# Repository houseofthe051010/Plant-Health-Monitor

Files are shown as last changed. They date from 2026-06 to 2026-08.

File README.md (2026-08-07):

# ESP32 Plant Health Monitor Rover

I built this to sample soil health from my garden to help plnat growth. This is just a prototype, not a reliable version yet, I will build another iteration but this is what I have currently. It is a fun educational toy to play with though.

## Features

* Autonomous
* Two-servo tank drive
* Seven servos total
  * Two continuous-rotation drive servos
  * Four arm position servos
  * One sample chamber closing servo
* Soil electrical conductivity measurement
* Temperature, humidity, pressure, and light measurements
* Ultrasound distance measurement
* Blackbox sensor data logging onboard esp32 flash

## Proof Pictures

Here is the demo video I have on the robot:

https://www.youtube.com/shorts/W9_TdJyh92A

### CAD Prototype

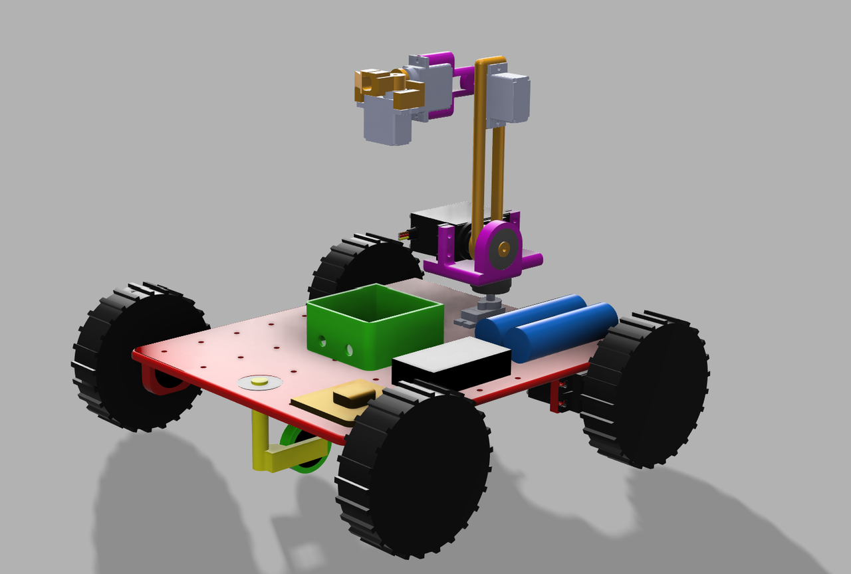
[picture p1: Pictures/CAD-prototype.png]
CAD Prototype


### Circuit Schematic

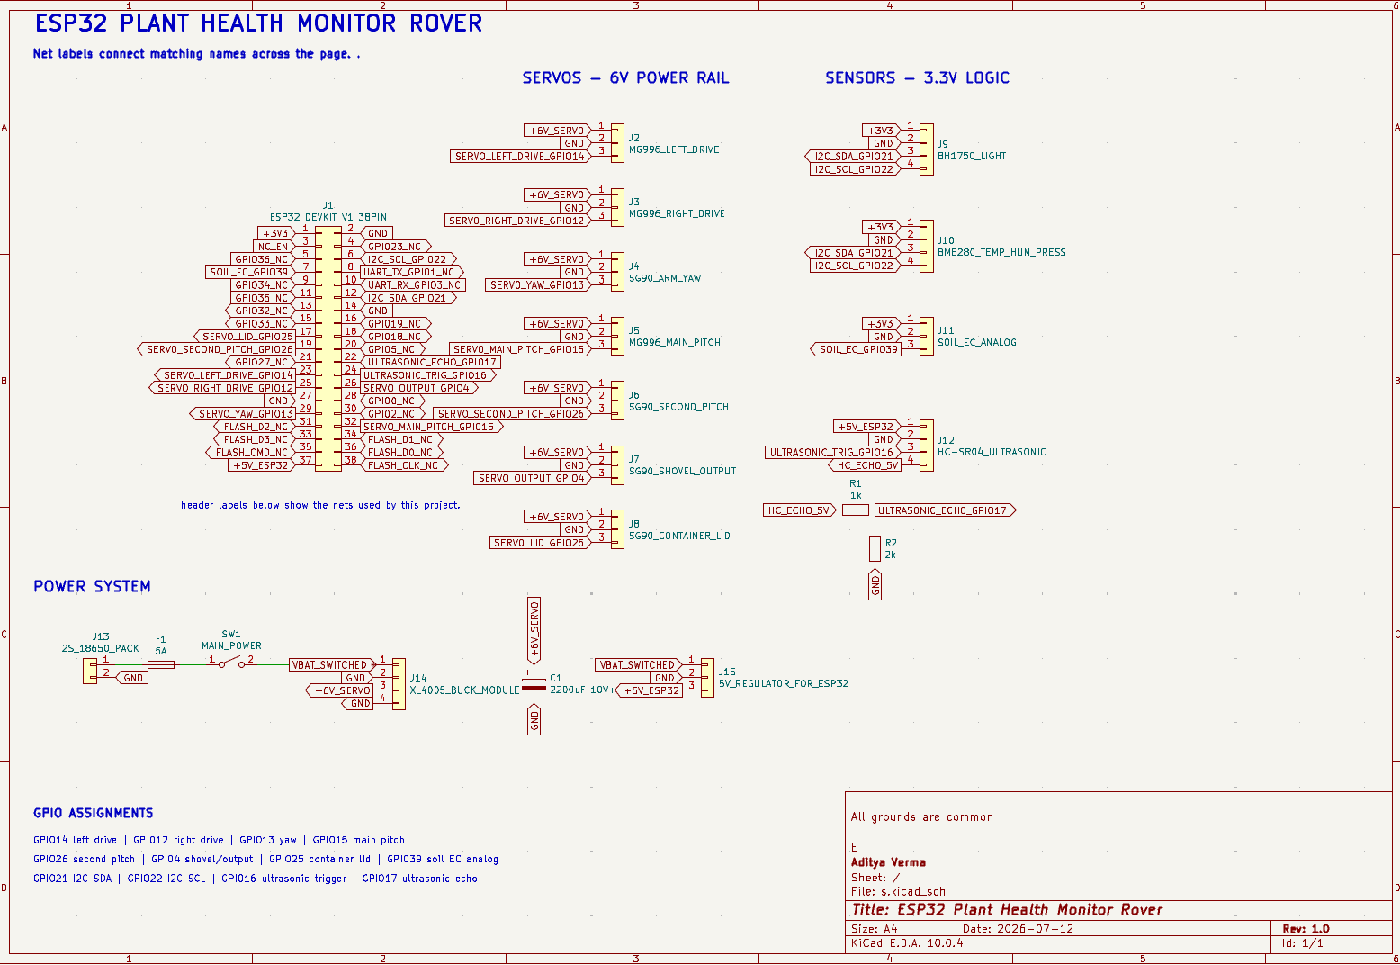
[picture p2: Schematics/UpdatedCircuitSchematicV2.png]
Updated Circuit Schematic


### Real-Life Prototype

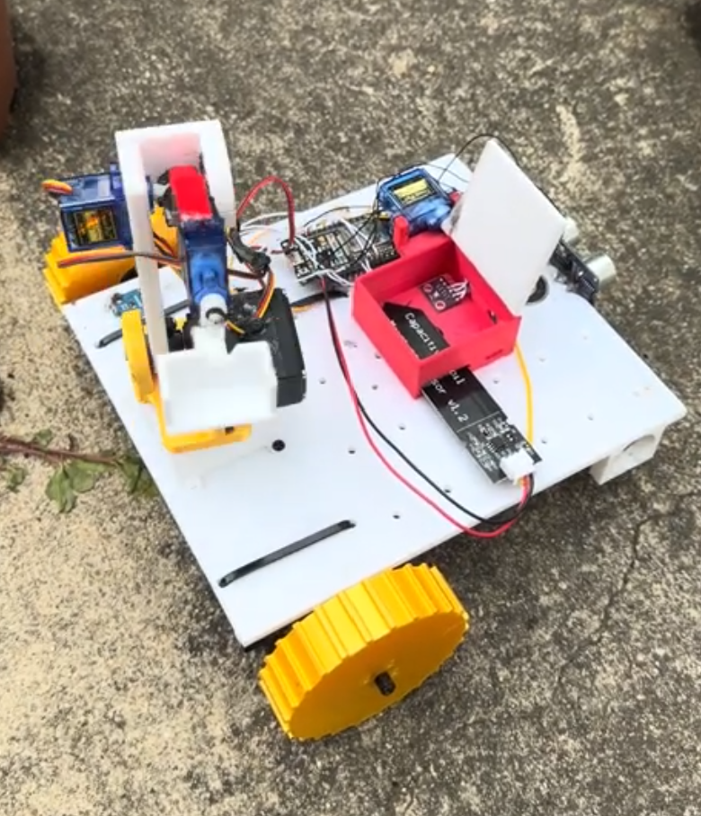
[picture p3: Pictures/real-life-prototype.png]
Real-Life Prototype


## Hardware Description

The rover utilizes ESP32 microcontroller. Tank drive is controlled using two PWM outputs, acting as continuous-rotation servos. Soil collection uses five additional PWM outputs to actuate servos of the arm and close the sample chamber.

Sensors include a BH1750 light sensor, a BME280 environmental sensor, an HC-SR04 ultrasound distance sensor, and an analog soil electrical conductivity sensor. Both BH1750 and BME280 are on the same I2C bus.

All the hardware data is logged to the ESP32's internal micropython filesystem and can be exported over USB.

## Bill of materials

| Category |  Quantity | Part | Purchase Link | Estimated Price |
| --- | ---: | --- | --- | ---: |
| Electronics | 1 | ESP32 | [AliExpress](https://www.aliexpress.us/item/3256812360578716.html) | $4.67 |
| Actuator | 2 | MG996 | [AliExpress](https://www.aliexpress.us/item/3256804365417662.html) | $9.28 |
| Actuator | 1 | MG996 180 Degree | [AliExpress](https://www.aliexpress.us/item/3256804365417662.html) | $4.64 |
| Actuator | 5 | SG90 | [AliExpress](https://www.aliexpress.us/item/3256806107378152.html) | $4.95 |
| Sensor | 1 | Ambient light sensor  | [AliExpress](https://www.aliexpress.us/item/3256809513329235.html) | $3.00 |
| Sensor | 1 | Environmental sensor  | [AliExpress](https://www.aliexpress.us/item/3256812547404758.html) | $5.85 |
| Sensor | 1 | Ultrasonic sensor | [AliExpress](https://www.aliexpress.us/item/3256810017345486.html) | $1.25 |
| Sensor | 1 | Soil EC sensor | [AliExpress](https://www.aliexpress.us/item/3256811685769454.html) | $13.29 |
| Power | 1 | Buck converter | [AliExpress](https://www.aliexpress.us/item/3256806558389509.html) | $1.46 |
| Power | 2 | 18650 cell | [AliExpress](https://www.aliexpress.us/item/3256811867524654.html) | $3.35 (2 of 16-pack at $26.77) |
| Power | 1 | 2S battery holder | [AliExpress](https://www.aliexpress.us/item/3256809135366720.html) | $0.99 |
| Power | 1 | Power switch | [AliExpress](https://www.aliexpress.us/item/3256807619399290.html) | $0.16 used (1 of 10-pack at $1.64) |
| Power | 1 | 2S battery charger | [AliExpress](https://www.aliexpress.us/item/3256805668198456.html) | $0.99 |
| Mechanical  | 5 | Ball bearing | [AliExpress](https://www.aliexpress.us/item/3256805609422387.html) | $8.06 (5-pack) |
| Mechanical  | As needed | M3 fasteners | [AliExpress](https://www.aliexpress.us/item/3256809672273859.html) | $14.88 assortment kit |
| Fabricated  | As needed | 3D filament allowance | [AliExpress](https://www.aliexpress.us/item/3256806989098121.html) | $3.00 |

## GPIO Mapping (needed for final wiring)

| Component | Purpose | ESP32 GPIO |
| --- | --- | ---: |
| Left drive motor | Drivetrain | 14 |
| Right drive motor | Drivetrain | 12 |
| Base yaw motor | Collection arm rotation | 13 |
| Base pitch motor | Main collection arm lift | 15 |
| Second pitch motor | Secondary collection arm | 26 |
| Shovel rotation motor | Soil collector/collector | 4 |
| Sample chamber motor  | Opens/closes sample chamber | 25 |
| Soil EC sensor | Analog soil electrical conductivity sensor | 39 |
| BH1750 | I2C SDA | 21 |
| BH1750 | I2C SCL | 22 |
| BME280 | I2C SDA | 21 |
| BME280 | I2C SCL | 22 |
| HC-SR04 ultrasonic | Trigger | 16 |
| HC-SR04 ultrasonic | Echo | 17 |

### BH1750 Light Sensor

Wired through I2C

| Pin | Connection |
| --- | --- |
| VCC | 3.3 V |
| GND | GND |
| SDA | GPIO21 |
| SCL | GPIO22 |

### BME280 Temp/Humidity/Air Pressure Sensor

Wired through I2C

| Pin | Connection |
| --- | --- |
| VCC | 3.3 V |
| GND | GND |
| SDA | GPIO21 |
| SCL | GPIO22 |

### HC-SR04 Ultrasonic Sensor

Distance sensor for navigation

| Pin | Connection |
| --- | --- |
| VCC | 3.3 V |
| GND | GND |
| Trigger | GPIO16 / RX2 |
| Echo | GPIO17 / TX2 |

### Analog Soil EC Sensor

Analog 

| Pin | Connection  |
| --- | --- |
| VCC | 3.3 V |
| GND | GND |
| Analog out | GPIO39 / VN |

## Servos

Seven servos in rover.

| Servo | Function | ESP32 GPIO |
| --- | --- | ---: |
| Left drivetrain  | Left drive motor for tank driving | 14 |
| Right drivetrain | Right drive motor for tank driving | 12 |
| Yaw | Collection arm rotation | 13 |
| Pitch base | Collection arm lifting | 15 |
| Pitch secondary  | Collection arm second joint | 26 |
| Shovel rotation  | Soil collector arm rotation | 4 |
| Chamber | Open/closes the soil collector chamber | 25 |

## Soil Sampling Movement Sequence

| Step | Action |
| ---: | --- |
| 1 | Base yaw to 500 µs |
| 2 | Second pitch to 1050 µs |
| 3 | Base pitch to 520 µs |
| 4 | Shovel rotation to 500 µs |
| 5 | Second pitch to 2330 µs |
| 6 | Shovel rotation to 2500 µs |
| 7 | Second pitch to 1080 µs |
| 8 | Chamber seal to 1000 µs |
| 9 | Base pitch to 1600 µs and second pitch to 2000 µs |
| 10 | Base yaw to 2500 µs |
| 11 | Base pitch to 1000 µs |
| 12 | Shovel rotation to 550 µs |
| 13 | Jittering shovel between 500 and 750 µs |
| 14 | Base pitch to 1600 µs and chamber seal to 2180 µs |

## Assembly Instructions

### Parts and Tools

Print all of the parts in [`CAD/Individual STLs`](CAD/Individual%20STLs) using the [recommended print settings](CAD/README.md).

* I strongly recommend getting the assembly and viewing it in order to accurately follow along with replicating this

### 1. Print and Prepare the Parts

1. Print and refine every part

### 2. Assemble the Base and Drivetrain

1. Begin with [`base_structure.stl`](CAD/Individual%20STLs/base_structure.stl), the large base.
2. Install [`front_wheel_hinge.stl`](CAD/Individual%20STLs/front_wheel_hinge.stl) onto the singular hole for the base, then fit a 608 bearing and [`front_caster_wheel.stl`](CAD/Individual%20STLs/front_caster_wheel.stl) into the caster.
3. Install the 2 MG996 motors for the drivetrain in their slots beneath the base, secure using M3 screws and hot glue if needed.

### 3. Build the Arm Yaw and Main Pitch Axes

1. Attach [`arm_yaw_servo_horn_attachment.stl`](CAD/Individual%20STLs/arm_yaw_servo_horn_attachment.stl) to the centered SG90 horn using m3 screws. use 608 on opposite side of the axis, press fit but use super glue if necessary.
2. Secure [`arm_yaw_servo_holder.stl`](CAD/Individual%20STLs/arm_yaw_servo_holder.stl) with M3s.
3. Fit [`arm_pitch_adapter.stl`](CAD/Individual%20STLs/arm_pitch_adapter.stl) onto the rod for the yaw servo holder
4. Install the MG996 in [`arm_pitch_servo_holder.stl`](CAD/Individual%20STLs/arm_pitch_servo_holder.stl) using m3 screws on the slots given for the arm pitch adapter.

### 4. Add the Second Pitch Joint and Tool Output

1. Place a 608 bearing on the opposite side of the joint.
2. Attach either the two-part output made from [`arm_output_attachment_part1.stl`](CAD/Individual%20STLs/arm_output_attachment_part1.stl) and [`arm_output_attachment_part2.stl`](CAD/Individual%20STLs/arm_output_attachment_part2.stl), or use [`arm_output_shovel_attachment.stl`](CAD/Individual%20STLs/arm_output_shovel_attachment.stl) for the soil-shovel configuration.

### 5. Install the Soil Container and Lid

1. Put [`Soil_container.stl`](CAD/Individual%20STLs/Soil_container.stl) behind the arm using included tapping screws.
2. Attach an SG90 horn to [`Soil_container_lid.stl`](CAD/Individual%20STLs/Soil_container_lid.stl), then attach the horn to servo.

### 6. Wiring

1. Refer to the pinout tables above
2. Wire in a way so the wire goes down the arm and motors don't get jammed.
3. Use 18650 battery holders (or solder the batteries for a 2S config)
4. Wire up to a switch
5. Wire to the XL4005
6. Configure at 5.8V
7. Use the XL4005 output rail to power the esp32, and all servos.
8. Place the temp/humidity + EC sensor in the container
9. Place the light sensor in an open spot on the robot
10. Place the ultrasonic on the front center of the robot, stabilize using hot glue
11. Wire everything to the 3.3v rail or 5v rail (if applicable) of the esp32.
12. Wire everything else according to PINOUT diagram for sensors.

## Setting Up Firmware

1. Use [Thonny](https://thonny.org/)
2. Use [Getting Started with Thonny MicroPython guide for ESP32 and ESP8266](https://randomnerdtutorials.com/getting-started-thonny-micropython-python-ide-esp32-esp8266/) to learn how to connect your ESP32 and upload code to it.
3. Connect ESP32 to computer and upload [`main.py`](SOURCE%20CODE/main.py) to the ESP32, and save it on the board as `main.py`.

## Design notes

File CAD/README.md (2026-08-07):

# CAD files

## Print settings

- Printer: Anycubic Kobra S1
- Material: PLA
- Infill: 20%
- Walls: 2

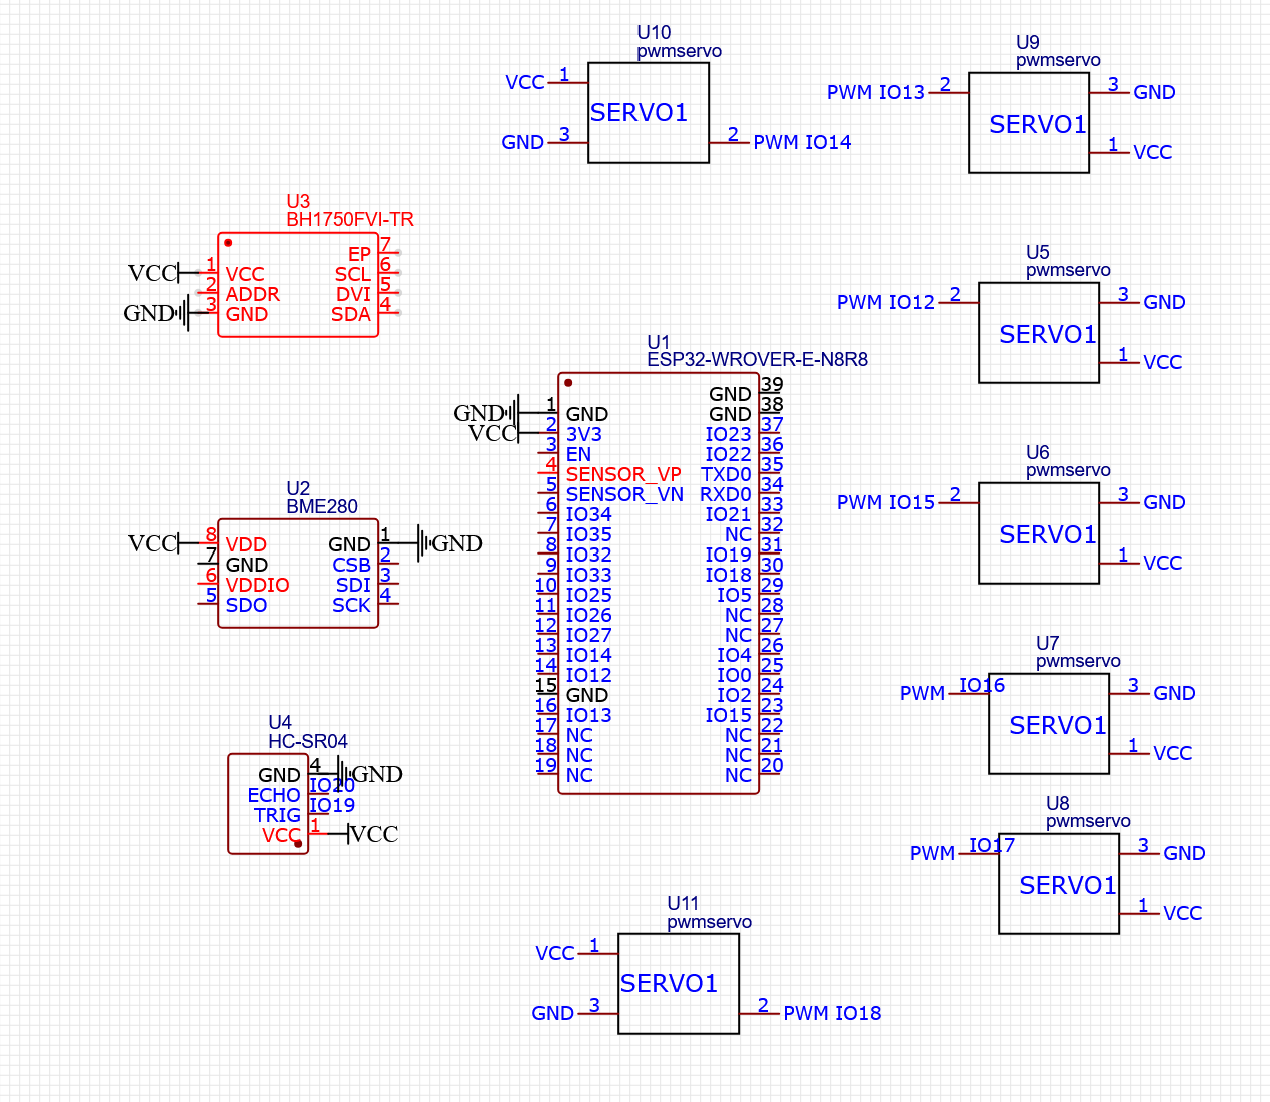
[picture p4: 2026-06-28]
Schematics/CircuitSchematic.png

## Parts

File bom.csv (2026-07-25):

Category | Quantity | Part | Link | Price
Electronics | 1 | ESP32 | https://www.aliexpress.us/item/3256812360578716.html | $4.67
Actuator | 2 | MG996 | https://www.aliexpress.us/item/3256804365417662.html | $9.28
Actuator | 1 | MG996 180 Degree | https://www.aliexpress.us/item/3256804365417662.html | $4.64
Actuator | 5 | SG90 | https://www.aliexpress.us/item/3256806107378152.html | $4.95
Sensor | 1 | Ambient light sensor | https://www.aliexpress.us/item/3256809513329235.html | $3.00
Sensor | 1 | Environmental sensor | https://www.aliexpress.us/item/3256812547404758.html | $5.85
Sensor | 1 | Ultrasonic sensor | https://www.aliexpress.us/item/3256810017345486.html | $1.25
Sensor | 1 | Soil EC sensor | https://www.aliexpress.us/item/3256811685769454.html | $13.29
Power | 1 | Buck converter | https://www.aliexpress.us/item/3256806558389509.html | $1.46
Power | 2 | 18650 cell | https://www.aliexpress.us/item/3256811867524654.html | $3.35 (2 of 16-pack at $26.77)
Power | 1 | 2S battery holder | https://www.aliexpress.us/item/3256809135366720.html | $0.99
Power | 1 | Power switch | https://www.aliexpress.us/item/3256807619399290.html | $0.16 used (1 of 10-pack at $1.64)
Power | 1 | 2S battery charger | https://www.aliexpress.us/item/3256805668198456.html | $0.99
Mechanical | 5 | Ball bearing | https://www.aliexpress.us/item/3256805609422387.html | $8.06 (5-pack)
Mechanical | As needed | M3 fasteners | https://www.aliexpress.us/item/3256809672273859.html | $14.88 assortment kit
Fabricated | As needed | 3d filament allowance | https://www.aliexpress.us/item/3256806989098121.html | $3

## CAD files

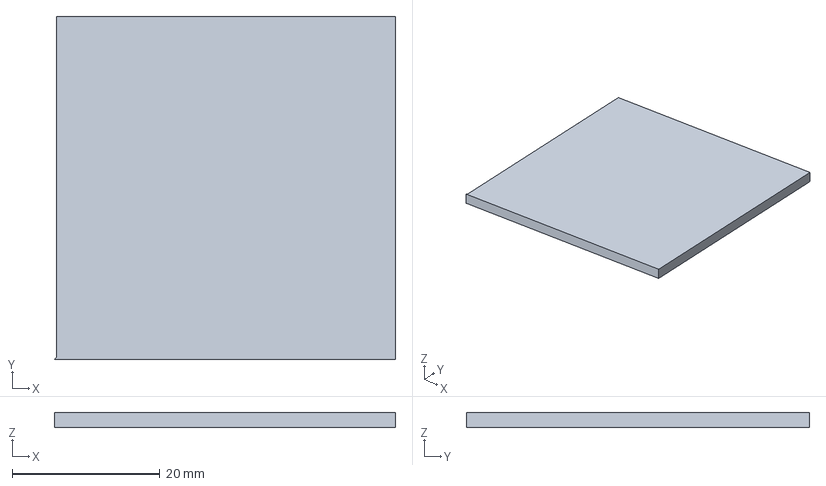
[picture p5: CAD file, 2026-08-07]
CAD/Individual STEP files/Soil_container_lid.step
46.2 x 46.5 x 2.00 mm

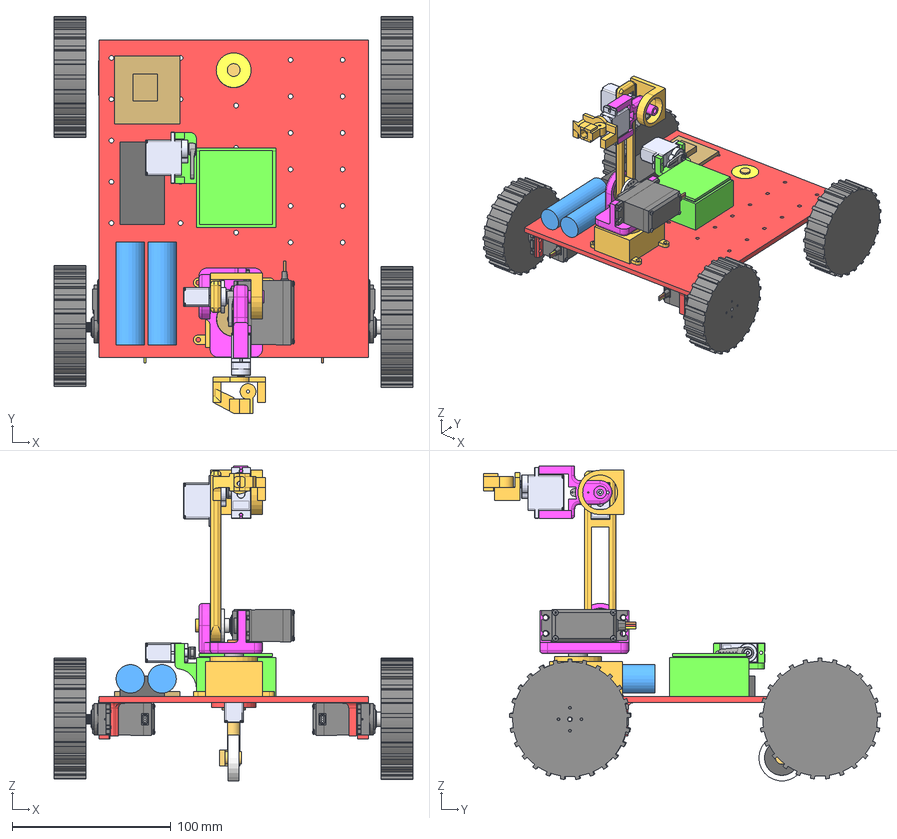
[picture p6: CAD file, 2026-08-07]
CAD/Source CAD/autonomous-soil-sampler-prototype.step
226.0 x 250.1 x 198.2 mm

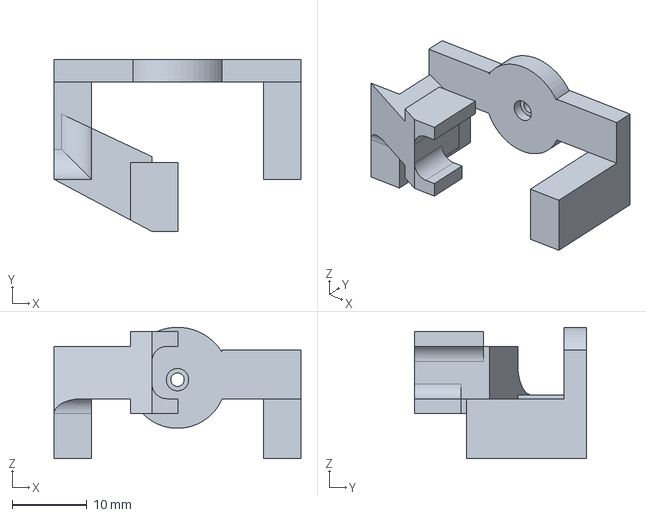
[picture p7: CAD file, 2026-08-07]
CAD/Individual STEP files/arm_output_attachment_part1.step
33.0 x 23.0 x 17.5 mm

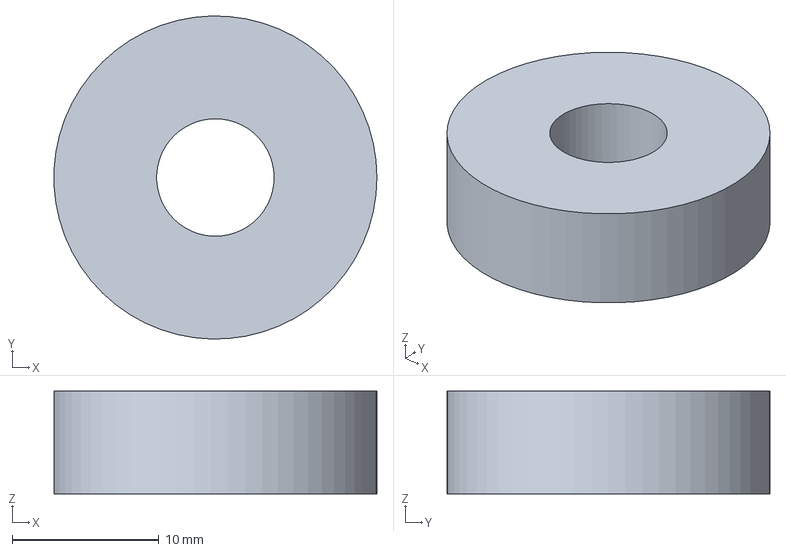
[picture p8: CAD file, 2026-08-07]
CAD/Individual STEP files/arm_pitch_adapter.step
22.0 x 22.0 x 7.00 mm

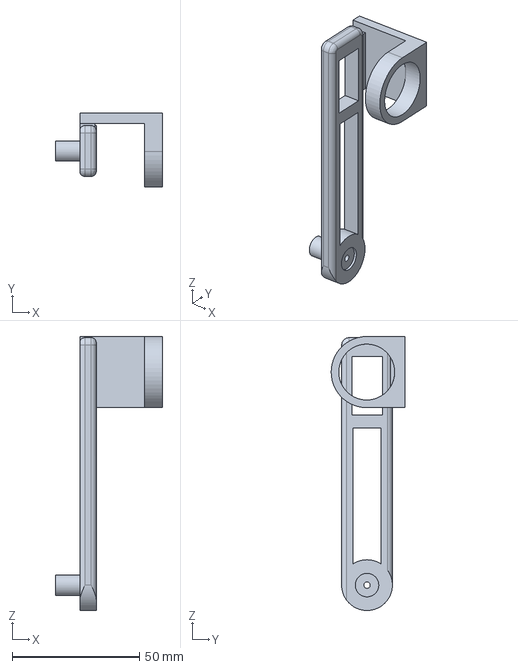
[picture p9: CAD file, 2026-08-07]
CAD/Individual STEP files/arm_pitch_servo_horn_attachment.step
42.0 x 29.0 x 107.8 mm

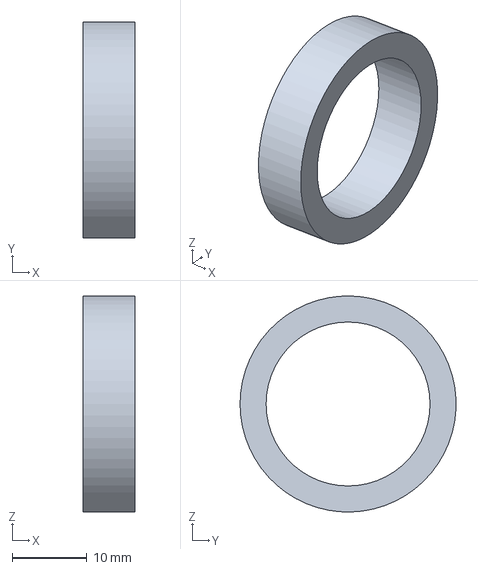
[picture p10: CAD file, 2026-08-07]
CAD/Individual STEP files/front_caster_wheel.step
7.00 x 29.0 x 29.0 mm

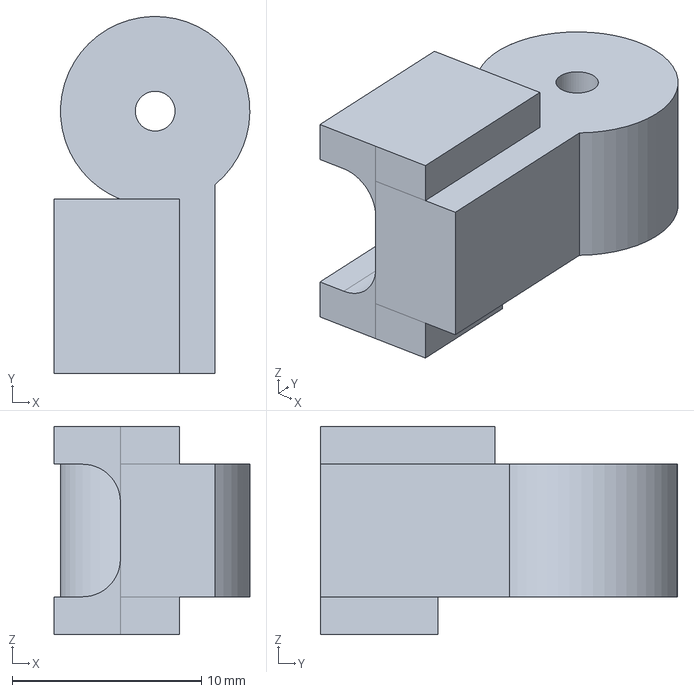
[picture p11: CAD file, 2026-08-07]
CAD/Individual STEP files/arm.step
10.3 x 18.8 x 11.0 mm

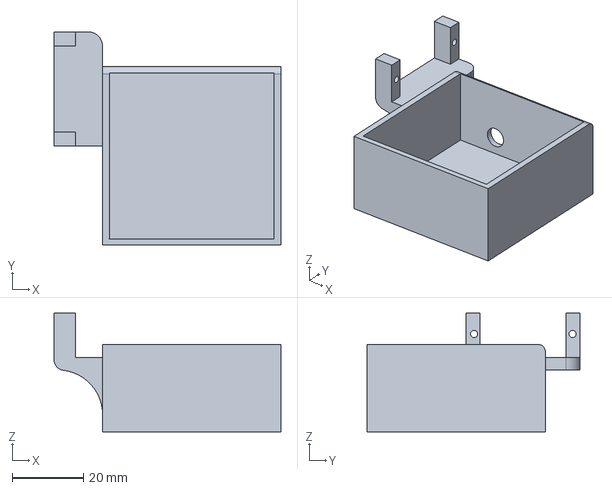
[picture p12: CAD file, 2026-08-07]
CAD/Individual STEP files/Soil_container.step
63.6 x 59.7 x 33.3 mm

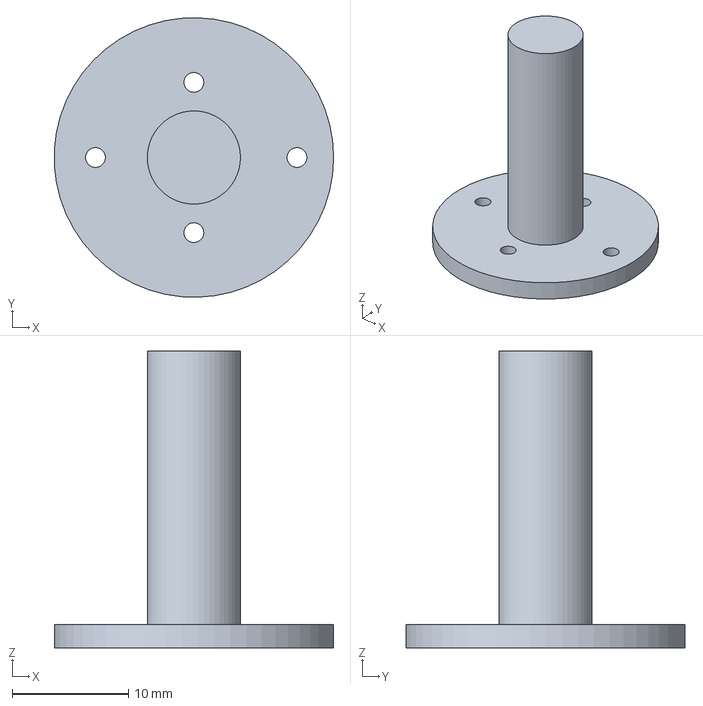
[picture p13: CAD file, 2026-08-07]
CAD/Individual STEP files/arm_yaw_servo_horn_attachment.step
24.0 x 24.0 x 25.5 mm

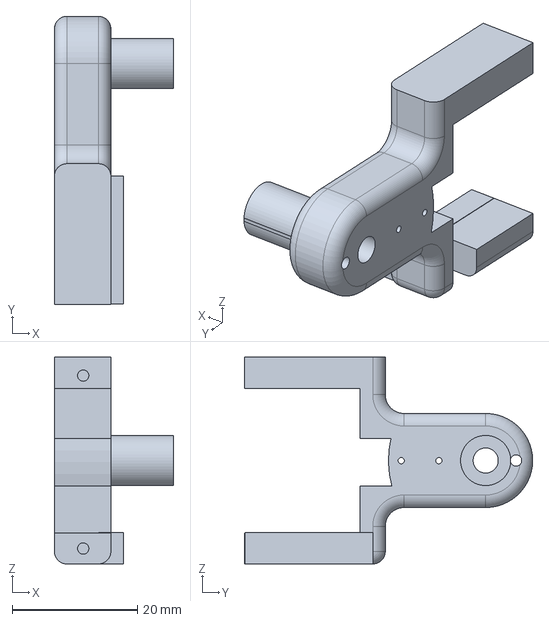
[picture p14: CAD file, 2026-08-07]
CAD/Individual STEP files/Arm_2nd_pitch_Horn_attachment.step
19.0 x 46.0 x 33.0 mm

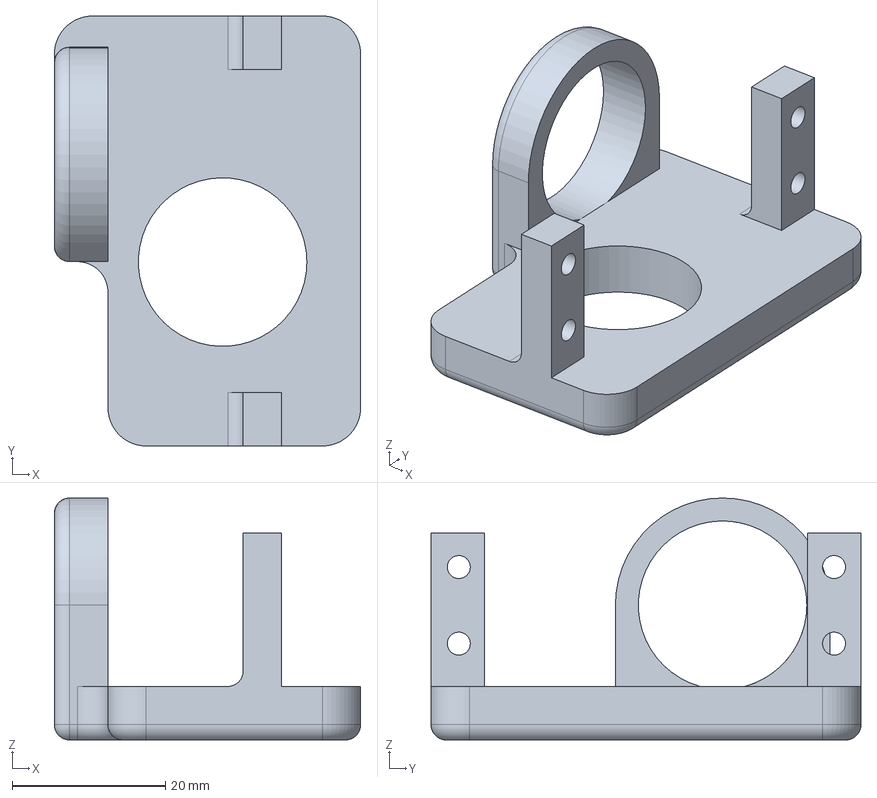
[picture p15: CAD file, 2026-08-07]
CAD/Individual STEP files/arm_pitch_servo_holder.step
40.0 x 56.1 x 31.6 mm

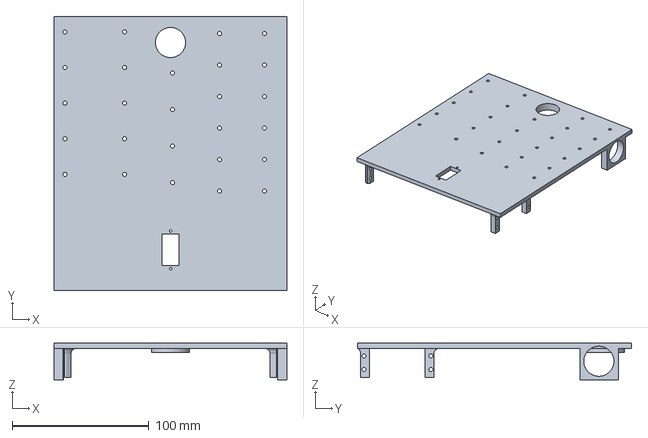
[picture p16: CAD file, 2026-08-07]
CAD/Individual STEP files/base_structure.step
170.0 x 200.0 x 27.0 mm

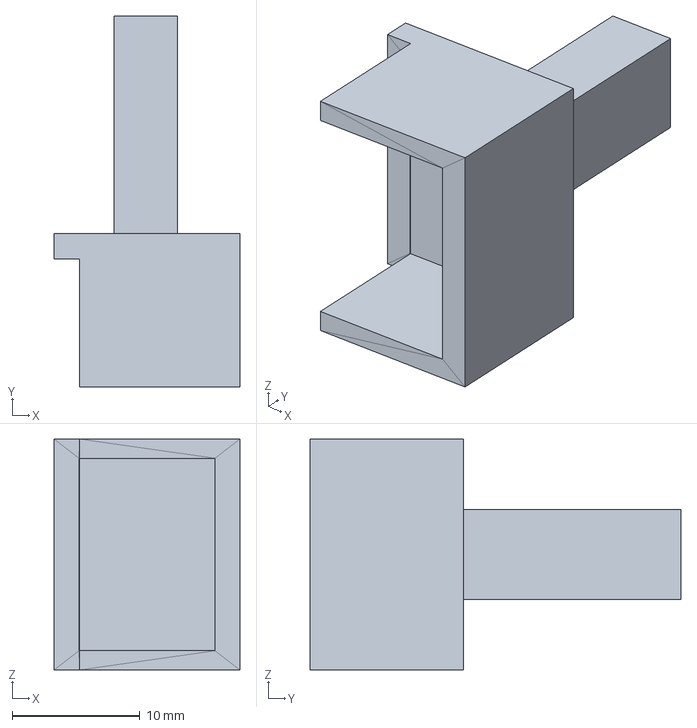
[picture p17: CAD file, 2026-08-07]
CAD/Individual STEP files/arm_output_shovel_attachment.step
14.5 x 29.0 x 18.1 mm

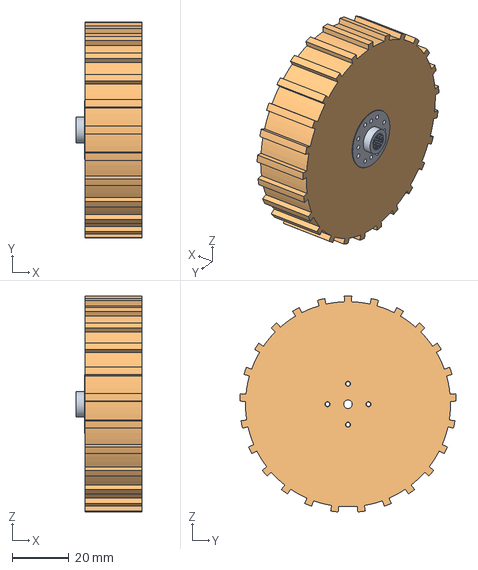
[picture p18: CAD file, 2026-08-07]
CAD/Individual STEP files/wheel.step
23.2 x 76.2 x 76.0 mm

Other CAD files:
CAD/Individual STEP files/arm_output_attachment_part2.step
CAD/Individual STEP files/front_wheel_hinge.step
CAD/Individual STEP files/arm_yaw_servo_holder.step
CAD/Individual STLs/Arm_2nd_pitch_Horn_attachment.stl
CAD/Individual STLs/Soil_container.stl
CAD/Individual STLs/Soil_container_lid.stl
CAD/Individual STLs/arm.stl
CAD/Individual STLs/arm_output_attachment_part1.stl
CAD/Individual STLs/arm_output_attachment_part2.stl
CAD/Individual STLs/arm_output_shovel_attachment.stl
CAD/Individual STLs/arm_pitch_adapter.stl
CAD/Individual STLs/arm_pitch_servo_holder.stl
CAD/Individual STLs/arm_pitch_servo_horn_attachment.stl
CAD/Individual STLs/arm_yaw_servo_holder.stl
CAD/Individual STLs/arm_yaw_servo_horn_attachment.stl
CAD/Individual STLs/base_structure.stl
CAD/Individual STLs/front_caster_wheel.stl
CAD/Individual STLs/front_wheel_hinge.stl
CAD/Individual STLs/wheel.stl
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

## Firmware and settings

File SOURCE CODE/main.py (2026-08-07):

from machine import ADC, I2C, Pin, time_pulse_us
from time import sleep_ms, sleep_us, ticks_ms
import os


LOG_FILE = "sensor_log.csv"
LOG_INTERVAL_MS = 60000

i2c = I2C(0, sda=Pin(21), scl=Pin(22), freq=100_000)
trigger = Pin(16, Pin.OUT, value=0)
echo = Pin(17, Pin.IN)
soil = ADC(Pin(39))
soil.atten(ADC.ATTN_11DB)


def u16(data, offset):
    return data[offset] | data[offset + 1] << 8


def s16(data, offset):
    value = u16(data, offset)
    return value - 65536 if value & 0x8000 else value


class BME280:
    def __init__(self, address):
        self.address = address
        c1 = i2c.readfrom_mem(address, 0x88, 26)
        c2 = i2c.readfrom_mem(address, 0xE1, 7)
        self.t = (u16(c1, 0), s16(c1, 2), s16(c1, 4))
        self.p = (u16(c1, 6),) + tuple(s16(c1, i) for i in range(8, 24, 2))
        h4 = c2[3] << 4 | c2[4] & 15
        h5 = c2[5] << 4 | c2[4] >> 4
        if h4 & 0x800:
            h4 -= 4096
        if h5 & 0x800:
            h5 -= 4096
        h6 = c2[6] - 256 if c2[6] & 0x80 else c2[6]
        self.h = (c1[25], s16(c2, 0), c2[2], h4, h5, h6)
        i2c.writeto_mem(address, 0xF2, b"\x01")
        i2c.writeto_mem(address, 0xF4, b"\x27")

    def read(self):
        data = i2c.readfrom_mem(self.address, 0xF7, 8)
        raw_p = data[0] << 12 | data[1] << 4 | data[2] >> 4
        raw_t = data[3] << 12 | data[4] << 4 | data[5] >> 4
        raw_h = data[6] << 8 | data[7]

        t1, t2, t3 = self.t
        a = (raw_t / 16384 - t1 / 1024) * t2
        b = (raw_t / 131072 - t1 / 8192) ** 2 * t3
        fine = a + b
        temperature = fine / 5120

        p1, p2, p3, p4, p5, p6, p7, p8, p9 = self.p
        a = fine / 2 - 64000
        b = a * a * p6 / 32768 + a * p5 * 2
        b = b / 4 + p4 * 65536
        a = (p3 * a * a / 524288 + p2 * a) / 524288
        a = (1 + a / 32768) * p1
        pressure = 0
        if a:
            pressure = (1048576 - raw_p - b / 4096) * 6250 / a
            pressure += (p9 * pressure * pressure / 2147483648 + p8 * pressure / 32768 + p7) / 16

        h1, h2, h3, h4, h5, h6 = self.h
        humidity = fine - 76800
        humidity = (raw_h - (h4 * 64 + h5 / 16384 * humidity)) * (
            h2 / 65536 * (1 + h6 / 67108864 * humidity * (1 + h3 / 67108864 * humidity))
        )
        humidity *= 1 - h1 * humidity / 524288
        return temperature, max(0, min(100, humidity)), pressure / 100


devices = i2c.scan()
bh1750 = 0x23 if 0x23 in devices else 0x5C if 0x5C in devices else None
bme_address = 0x76 if 0x76 in devices else 0x77 if 0x77 in devices else None
bme = BME280(bme_address) if bme_address else None

if bh1750:
    i2c.writeto(bh1750, b"\x10")
    sleep_ms(180)


def read_light():
    data = i2c.readfrom(bh1750, 2)
    return (data[0] << 8 | data[1]) / 1.2


def read_distance():
    trigger.value(1)
    sleep_us(10)
    trigger.value(0)
    pulse = time_pulse_us(echo, 1, 30_000)
    return pulse / 58 if pulse > 0 else None


def value_or_blank(function):
    try:
        value = function()
        return "" if value is None else "{:.2f}".format(value)
    except Exception:
        return ""


try:
    os.stat(LOG_FILE)
except OSError:
    with open(LOG_FILE, "w") as file:
        file.write("uptime_ms,light_lux,temp_c,humidity_pct,pressure_hpa,distance_cm,soil_raw\n")


while True:
    if bme:
        try:
            temperature, humidity, pressure = bme.read()
            environment = tuple("{:.2f}".format(x) for x in (temperature, humidity, pressure))
        except Exception:
            environment = ("", "", "")
    else:
        environment = ("", "", "")

    soil_raw = soil.read_u16() if hasattr(soil, "read_u16") else soil.read()
    row = [
        str(ticks_ms()),
        value_or_blank(read_light) if bh1750 else "",
        environment[0],
        environment[1],
        environment[2],
        value_or_blank(read_distance),
        str(soil_raw),
    ]
    line = ",".join(row)
    with open(LOG_FILE, "a") as file:
        file.write(line + "\n")
    print(line)
    sleep_ms(LOG_INTERVAL_MS)

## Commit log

2026-07-12 readme updated
    [arm.stl, arm_output_shovel_attachment.stl, wheel.stl]
2026-08-07 final polishes
    [bom.csv]
2026-08-07 assembly polishes
